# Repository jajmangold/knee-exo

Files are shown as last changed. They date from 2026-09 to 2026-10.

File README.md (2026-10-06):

<div align="center">

# Powered Knee Orthosis

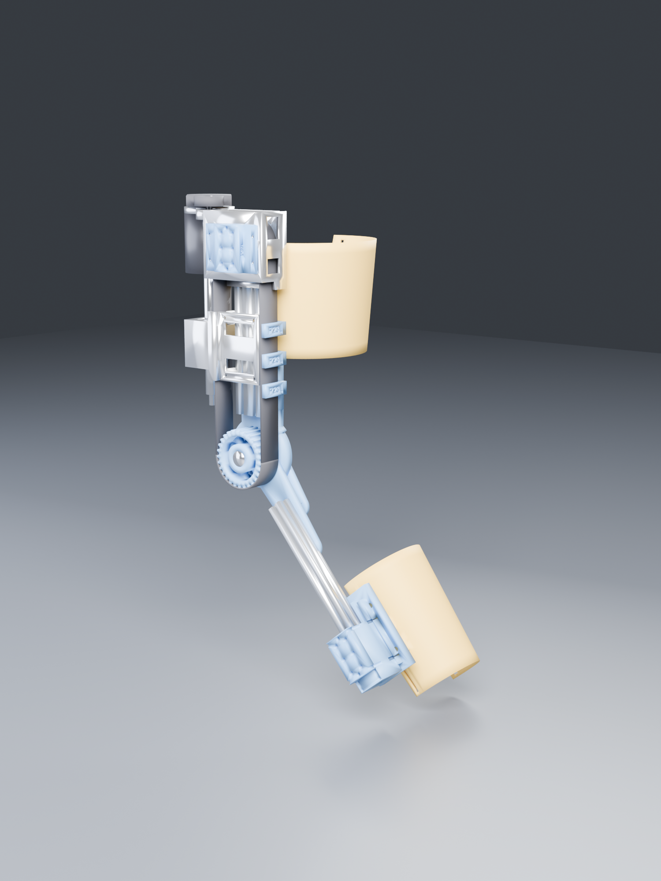
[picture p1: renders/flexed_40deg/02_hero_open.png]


<sub>Cycles render · 512 samples · the CAD itself is below</sub>

**28.2 N·m** · **36.92 mm moment arm, constant at every angle** · **86 mm proud of the knee** · **0 clashes in 107 poses**

</div>

---

> [!WARNING]
> **This is not a validated medical device.** No FEA has been run — every number here is a
> hand calculation, and the ones that matter are shown so you can check them. Cuffs are
> sized nominally for 1.75 m / 80 kg **against a cone phantom, not a measured limb** — see
> the cuff section below. Do not fit this to anyone without a clinician in the loop and a
> bench test under the loads listed.

## The problem

A patient a year out from knee surgery, struggling with walking and — particularly —
stairs. Stair ascent is the hard case: it demands the largest knee extension moment of any
activity of daily living, roughly **1.05 N·m/kg**, and it is exactly where a weak knee
buckles.

The target is **~30% assist**, not replacement. At 80 kg that is **28.2 N·m**, over a range
of motion of **−2° to 104°** — full extension to a deep enough flexion to sit down.

Everything else in this repository follows from those two numbers.

---

## It moves like this

A full flexion cycle, 0° → 104° → 0°, from 32 poses exported straight out of FreeCAD and
rendered in **Cycles**. Left: the mechanism. Right: the same cycle with the fairings on.

<div align="center">
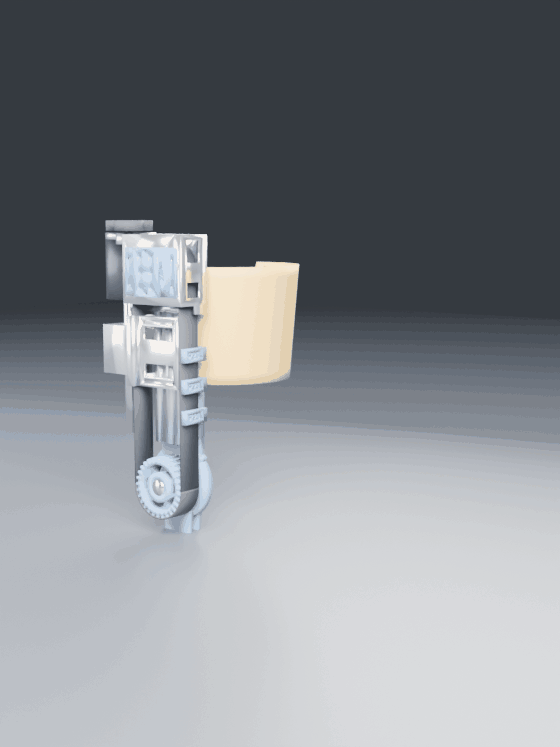
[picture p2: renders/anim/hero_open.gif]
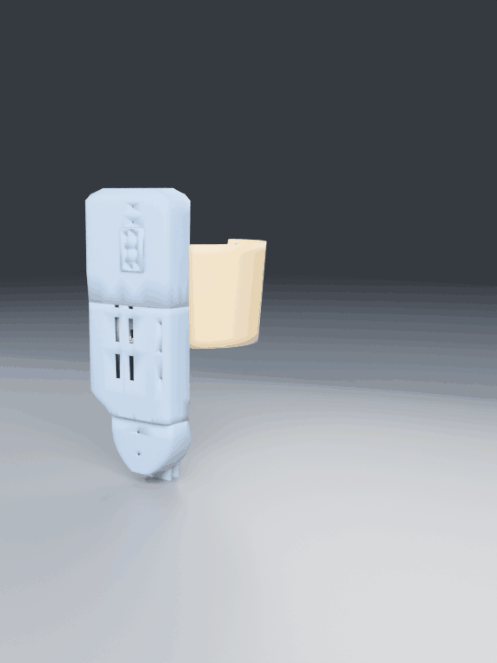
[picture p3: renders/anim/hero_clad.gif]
 
</div>

Watch the single carriage in the left animation. It is clamped to one strand of a closed
belt loop running over two identical 29T pulleys — the knee capstan and an idler. Move the
clamp by *d* and the belt circulates by *d*, turning the knee by *d/R*. That is the whole
idea, and it is why one screw does what two opposed ones used to.

<div align="center">
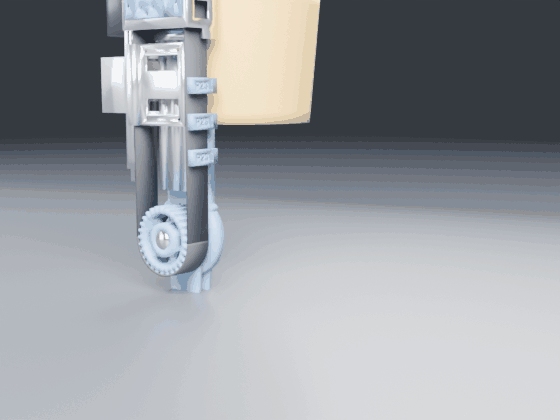
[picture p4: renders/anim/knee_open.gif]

</div>

---

## How it works

<div align="center">
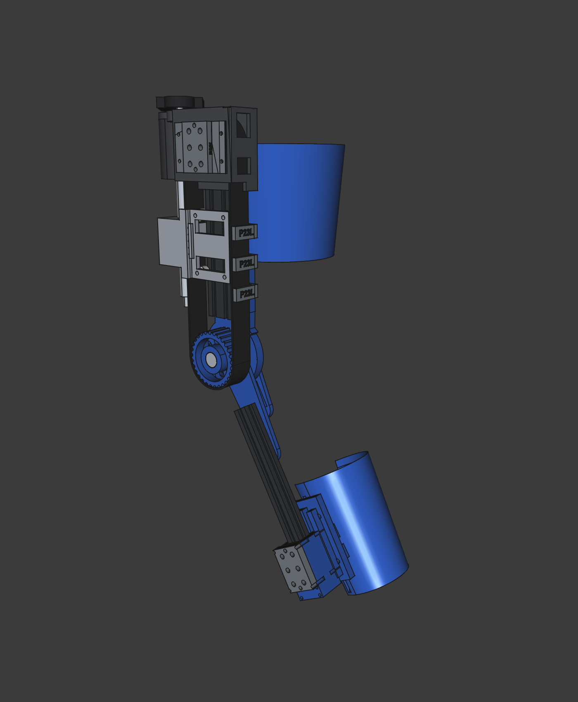
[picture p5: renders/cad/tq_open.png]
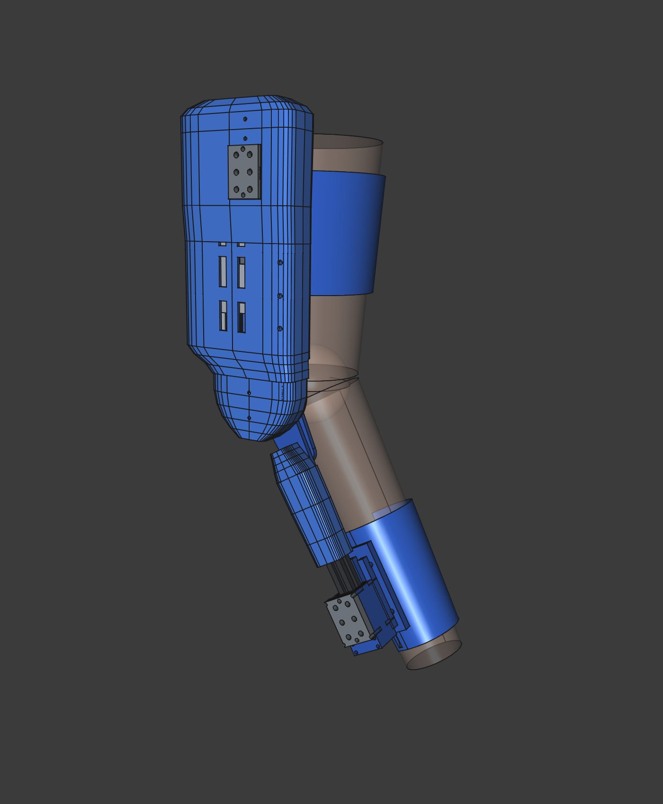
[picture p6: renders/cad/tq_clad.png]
 
<br><sub>FreeCAD viewport · mechanism, and the same thing clad on the reference limb</sub>
</div>

A **belt capstan** at the knee, driven by **one ball screw** through a closed belt loop:

| | |
|---|---|
| **Axes** | +Y proximal, **Z is the knee axis** so Z is medial-lateral, +X posterior. This is a **lateral upright** — the whole device hangs off the outside of the leg |
| **29T HTD-8M pulley** | concentric with the knee pin, integral with the shank hinge fork |
| **A second, identical 29T pulley** | an idler on the centreline at Y 255. Equal pulleys are what put both belt strands at exactly X = ±36.9 |
| **Closed HTD-8M loop, 742 mm** | over those two pulleys. Loop length is `2πR + 2·Y_idler`, independent of carriage position |
| **One carriage, clamped to one strand** | move the clamp by *d* and the belt circulates by *d*, turning the knee by *d/R* |
| **One SFU1610 RH screw at X = −62** | no left-hand thread anywhere in the build |
| **20×40 V-slot rail, 151 mm** | aluminium V-wheel gantry on mini wheels at the \|X\| 20 corners |
| **1:1.6 overdrive, motor → screw** | 32T : 20T HTD-5M. This is where the ratio is set, not the idler |
| **C6374 170 Kv BLDC + MKS XDRIVE MINI** | ODrive v3.6 clone, torque control only, never position |

Total ratio **14.5 : 1**. The idler does not gear anything — it carries no torque, and
`2πR/lead` with the belt loop alone gives 23.2 : 1. The **link belt** supplies the rest,
and it is the right place to do it: sitting on the motor side of the ball screw's own
mechanical advantage, it carries 85 N where the capstan loop carries 764, so gearing there
costs the belt, the nut, the screw and the idler bracket nothing at all. That is what
finally reached the 14.5 : 1 this design wanted, without an SFU1616 — see
[`scripts/404_link_ratio.py`](scripts/404_link_ratio.py). What the second pulley buys is
the *return path* that lets one carriage do the work of two. How that came about, and the 725 g it saved, is
[further down](#where-this-design-is-weak).

### Why the differential is exact, not approximate

This is the part worth understanding, because it is what makes the whole architecture work.

Belt length from anchor A, around the pulley, to anchor B is:

```
L = Ya + πR + Yb
```

With a **fixed 180° wrap**, `πR` is a constant, so conservation of belt length reduces to:

```
Ya + Yb = const
```

Two equal-pitch left- and right-hand screws on one shaft give exactly `dYa = −dYb`. That
is not an approximation of the constraint — it **is** the constraint, expressed in
hardware. The belt cannot go slack and it cannot be over-tensioned by driving the motor,
because the mechanism has no way to change `Ya + Yb` at all.

Here is that being true, in the model. Same camera, same scale, orthographic; only the
knee angle differs. Watch carriage **A** (left) and **B** (right) trade places:

<div align="center">
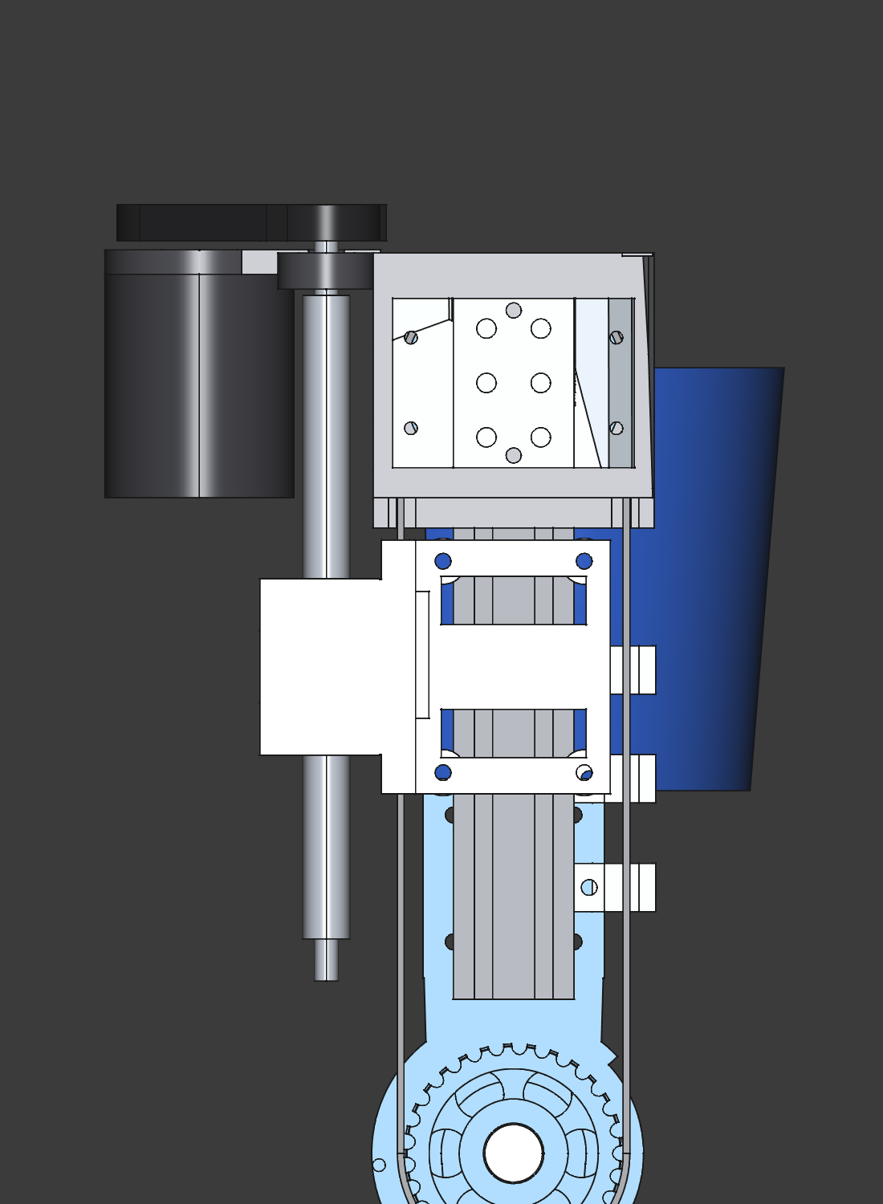
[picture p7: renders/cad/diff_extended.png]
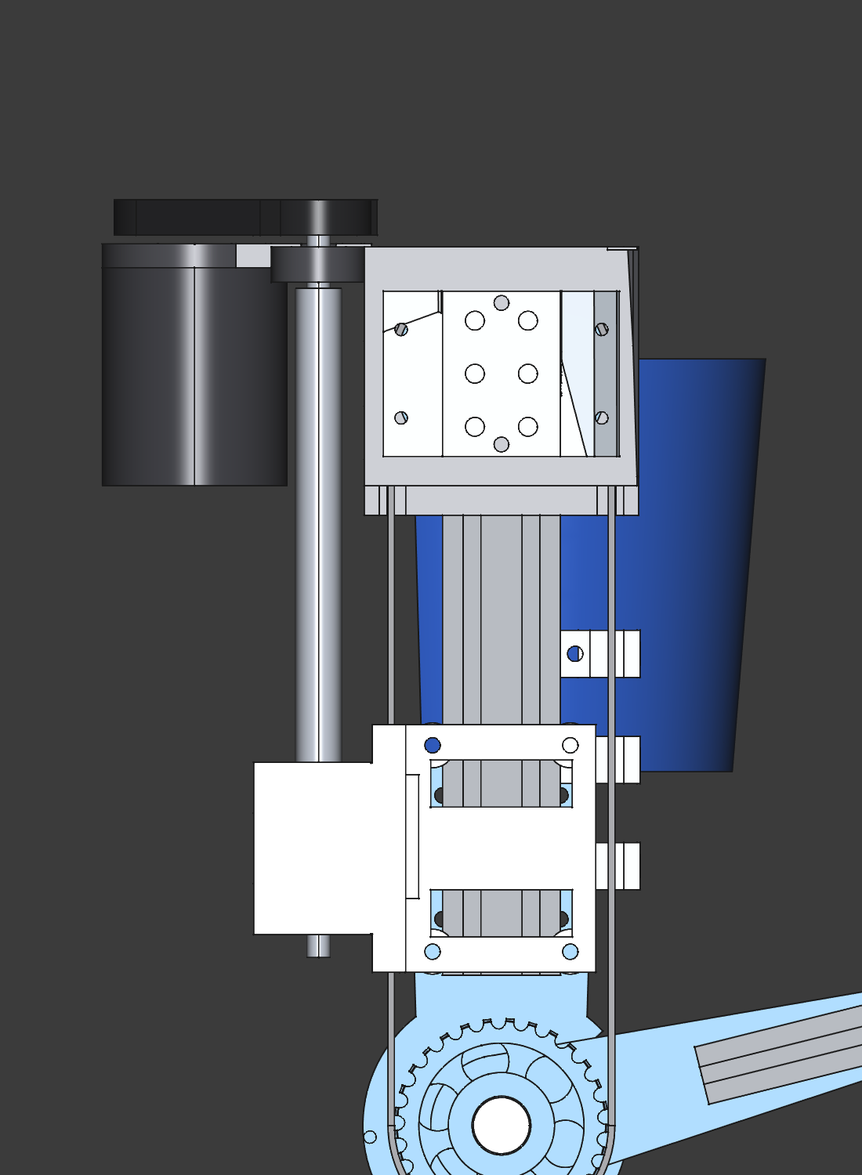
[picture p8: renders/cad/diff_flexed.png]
 
<br><sub>FreeCAD · full extension (θ = 0°) and full flexion (θ = 104°).
A drops 68.3 mm, B rises 68.3 mm, the sum never moves.</sub>
</div>

Verified constant at **242.00 mm** across all 107 poses, and re-checked on every one of the
32 animation frames above:

```
f00 theta   0.00  carrA 152.00  carrB 138.00  sum  242.00
f07 theta  41.86  carrA 125.03  carrB 164.97  sum  242.00
f15 theta 103.00  carrA  85.62  carrB 204.38  sum  242.00
f23 theta  62.14  carrA 111.95  carrB 178.05  sum  242.00
```

**This only works because both runs are parallel.** With an angled run, `Ya + Yb` becomes
nonlinear in θ and the two rigid screws fight the belt. Parallel runs are not a styling
choice; they are load-bearing on the maths.

### The second gift: a constant moment arm

<div align="center">
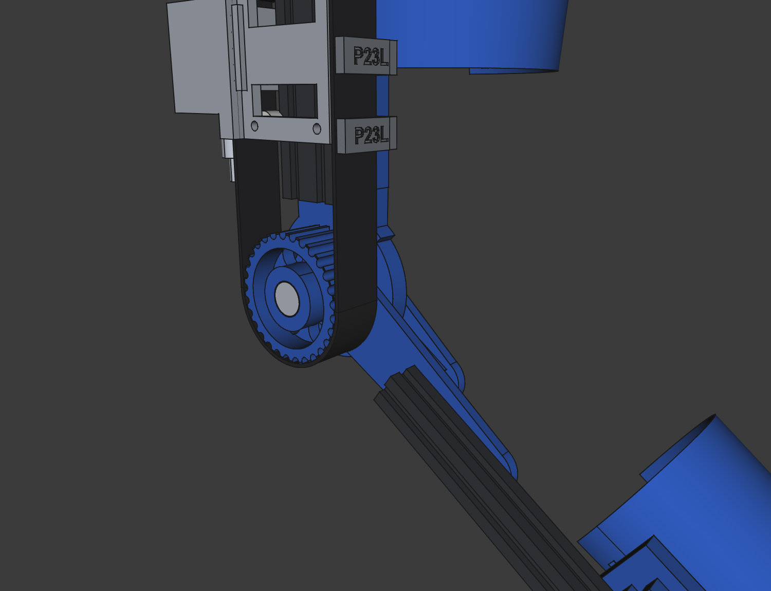
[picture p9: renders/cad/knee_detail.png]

<br><sub>FreeCAD · the 29T capstan, the yoke, and the 180° wrap</sub>
</div>

A capstan's moment arm is its pitch radius, and a pitch radius does not change with angle.
So the device delivers **36.92 mm at 0° and 36.92 mm at 104°** — no dead spots, no torque
curve to compensate for in software, no linkage singularity. Compare a slider-crank, whose
effective arm collapses towards the ends of travel; that was the first architecture tried
here, and it is in the graveyard below partly for this reason.

---

## Four architectures that did not survive

Each of these was **built and measured**, not discarded on paper. The number in the last
column is the one that killed it.

| # | Approach | Why it died | Killer number |
|---|---|---|---|
| 1 | Rigid rod + rod ends to a clevis | Clevis put the full load in tension across two M5 T-nuts, over a 75 mm path crossing two bolted joints | **1269 N**, SF **1.16** |
| 2 | Pure belt drive, motor → knee | A single stage cannot give the ratio. 65T/14T = 4.67:1 needs 6.04 N·m from a motor that peaks at 3.5 | **6.04 vs 3.5 N·m** |
| 3 | Screw + belt + constant-force spring | Spring was pure parasitic loss, gave an unpowered flexion bias, and a skipped tooth loses position permanently | **119 N** loss, **4.2 N·m** bias |
| 4 | C-Beam 80×40 rail | Belt runs are 71 mm apart but the rail half-width is 40 mm, so the belt had to be *lifted over* the rail — giving a 57 mm hub cantilever | pin **SF 1.01**, hub **SF 0.51** — failing |

Architecture 4 is the instructive one. Switching to a C-beam looked like an upgrade: a
stiffer rail, an enclosed channel to hide the belt in. But the C-beam is *wider* than the
20×60, and once the rail is wider than the belt run spacing, the belt has nowhere to go but
over the top. That 57 mm cantilever took the PETG hub to a **safety factor of 0.51** — it
would have snapped.

The fix was to go **back** to a narrower rail and run the belt down beside it. Current
state, with the belt at the same height as the rail:

| | C-beam, belt lifted | 20×60, belt beside |
|---|---|---|
| Hub moment | 62.2 N·m | **18.5 N·m** |
| Knee pin | M10, 633 MPa, SF 1.01 | **M12, SF 5.9** |
| PETG hub | 29.4 MPa, **SF 0.51** | **SF 3.7** |

### The measurement that caused it

I had been assuming for some time that the two belt runs partly cancel at the pin. They do
not. **Both runs leave the pulley on the proximal side, so their tensions add** — 764 N of
differential plus 150 N of pretension on each side gives **1091 N net into the knee pin**.
Checking that one sign is what exposed the lifted-belt layout as unbuildable.

---

## Two findings worth keeping

**The seat law.** Any point on the shank swings to approximately its own radius
*posteriorly* at 90° flexion. So if you do not want a part digging into a chair when the
patient sits, keep its radius from the knee axis below the seat clearance. This caps the
pulley at **R ≤ 52 mm** — the 36.92 mm capstan passes easily, while the old rod pivot at
**R = 74.7 mm** did not, and that is why sitting down in architecture 1 was unpleasant.

**Belt tension cannot be servo-controlled, and never could.** The shaft fixes `Ya + Yb`, so
turning the motor changes tension *not at all*: there is no control authority, and no
sensor can close that loop. Pretension is invisible at the motor too, because it pulls both
carriages distally and the opposite screw hands cancel the torques exactly.

Worse, the differential is **too stiff to hold pretension**. 150 N is only 0.27–0.53 mm of
belt stretch, while a new HTD belt beds in by 0.7–1.8 mm — so the pretension would simply
vanish during break-in, with nothing able to take it up.

Hence the **sprung anchor**: 3 mm of travel at ~500 N/mm, which absorbs bedding-in in one
twentieth of the travel the abandoned constant-force drum needed. Cost: 1.58 mm of lost
motion, **2.45° of knee angle**. Bonus: a Hall sensor on that slide reads
its deflection as **live belt tension**, which is the only tension measurement the machine
can make.

---

## Drivetrain

Everything below is derived in [`scripts/300_drivetrain.py`](scripts/300_drivetrain.py) —
one file, so there is a single place to change an assumption.

### The screw lead is the biggest open decision

Reflected rotor inertia scales with the **square** of the total knee→motor ratio. This is
what the patient feels whenever the motor is off: a dead battery, a fault trip, or simply
the free-swing phase of every single step.

| Screw | Ratio | Screw revs over ROM | Reflected J | **vs. the limb's own J** | Peak current | Nut OD |
|---|---|---|---|---|---|---|
| SFU1605 | 46.4 | 13.66 | 0.667 kg·m² | **2.22×** | 12.4 A | 28 mm |
| **SFU1610 — built** | 23.2 | 6.83 | 0.167 kg·m² | **0.56×** | 24.8 A | 36 mm |
| **SFU1616 — target** | 14.5 | 4.27 | 0.065 kg·m² | **0.22×** | 39.7 A | 36 mm |
| SFU1620 | 11.6 | 3.42 | 0.042 kg·m² | 0.14× | 49.6 A | 40 mm |

At **SFU1605 the leg would feel roughly three times as heavy to swing as it does bare.**
For someone already struggling to walk, that is a worse device than no device at all.

And you cannot gear your way out of it. Only the **total** ratio matters, so "SFU1620 plus
a 4:1 reduction" is inertially identical to SFU1605 direct. The only levers are a lower
total ratio (which costs motor current) or a lower-inertia rotor.

**SFU1610 is the right answer, and it is what the model now carries.**

This used to carry a caveat that the 1610 nut fouled the belt by 1.1 mm and the screws had
to move out to ±62. That was wrong, and wrong in an instructive way: it compared the nut
and the belt *projected onto the X axis* — 58 − 18 = 40 against the belt's outer face, taken
then as 41.1 and since [`423_belt_envelope.py`](scripts/423_belt_envelope.py) as **38.46** — and
never checked whether they share any length. They do not. The nut sits at
`carrA + 36` and its belt run ends at `carrA − 24`, a constant **60 mm apart at every
pose, by construction**. Swept over all 107 poses the overlap is **0.000 cm³ for OD 28,
OD 36 and OD 40 alike**.

What *does* run alongside the belt is the screw shaft, and at r = 7.9 it stays clear until
|X| < 49.

Building it ([`240_nut1610.py`](scripts/240_nut1610.py) and
[`241_fixups.py`](scripts/241_fixups.py)) took three changes, two of which only the sweep
found:

- **The carriage body** has to grow to X 34…80, Z 84…128 to capture a 36 mm bore with a
  3.8 mm wall on all three faces.
- **Its top-outboard corner then clipped `P21` by 0.495 cm³** — *trap 2 again*: a
  superellipse is not 84 wide everywhere, and by Z = 128 its half-width has fallen to 83.3
  and its inner wall to ~80.3. Rather than guess a chamfer, the carriage is simply **cut by
  `P21`**. The fairing's section is constant over Y 58…300, which covers the whole travel
  band, so one cut clears every pose and the chamfer matches the fairing exactly.
- **Carriage B then hit the thigh cuff, 8.67 cm³** at X 34…70, Z 84…88. The body had to
  drop to Z = 84 for the nut and the cuff tops out at 88 — but only on the +X side, where
  it wraps further round the limb, which is why carriage A was clean and only B clashed.
  The cuff bolts to the rail's medial face at |X| < 30, so the wrap-around material out at
  X 32…82 gets a corridor cut through it.

Swept over all 107 poses: **zero hard-part clashes**, knee standoff unchanged at 86 mm.

### Motor

| | |
|---|---|
| Motor | C6374 outrunner, **170 Kv**, 14-pole (verify: count the magnets) |
| Torque constant | 0.0562 N·m/A |
| Shaft torque | 1.39 N·m at 10 mm lead · 2.23 N·m at 16 mm |
| Peak current | **24.8 A at 10 mm** · 39.7 A at 16 mm |
| Peak speed | 1160 rpm at 10 mm · 725 rpm at 16 mm |
| No-load at 38.4 V | 6528 rpm — we use 18% of it |
| Controller | MKS XDRIVE MINI, ODrive v3.6 clone, 12–56 V, ~40 A, fw 0.5.1 |
| Owned | 4 motors, 4 drives — a bilateral build is a mechanical parts question only |

### Energy

Lifting 80 kg by a 170 mm stair rise is 133 J. The knee does about half; the exo supplies
40% of that at 55% wall-to-shaft — so **49 J per step, electrical**.

| Use | Draw | Hoverboard 360 Wh | Ebike 504 Wh |
|---|---|---|---|
| Stair climbing, 1 step/s | 57 W | 6.4 h | 8.9 h |
| Level walking | 23 W | 15.5 h | 21.6 h |
| Mixed daily use | 12 W | 30.9 h | 43.3 h |

**Energy is not the constraint.** Both packs comfortably outlast a day, so the battery gets
chosen for its *mount*, not its capacity — see [`docs/BOM.md`](docs/BOM.md) §7.

---

## Packaging

<div align="center">
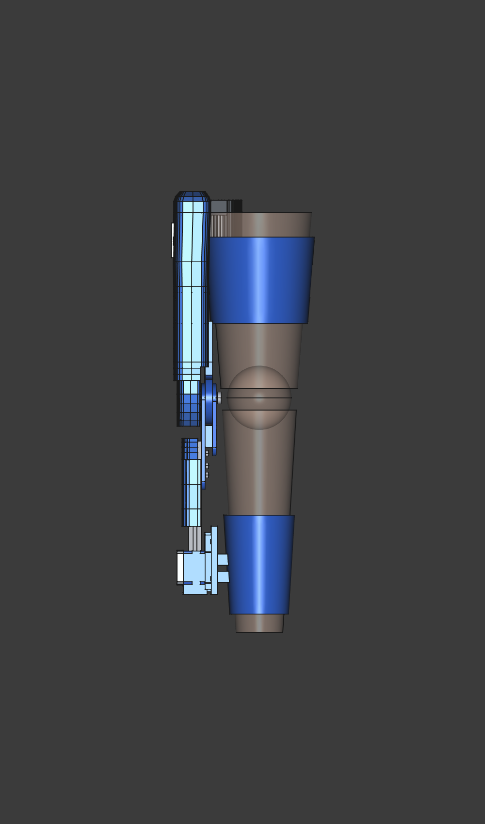
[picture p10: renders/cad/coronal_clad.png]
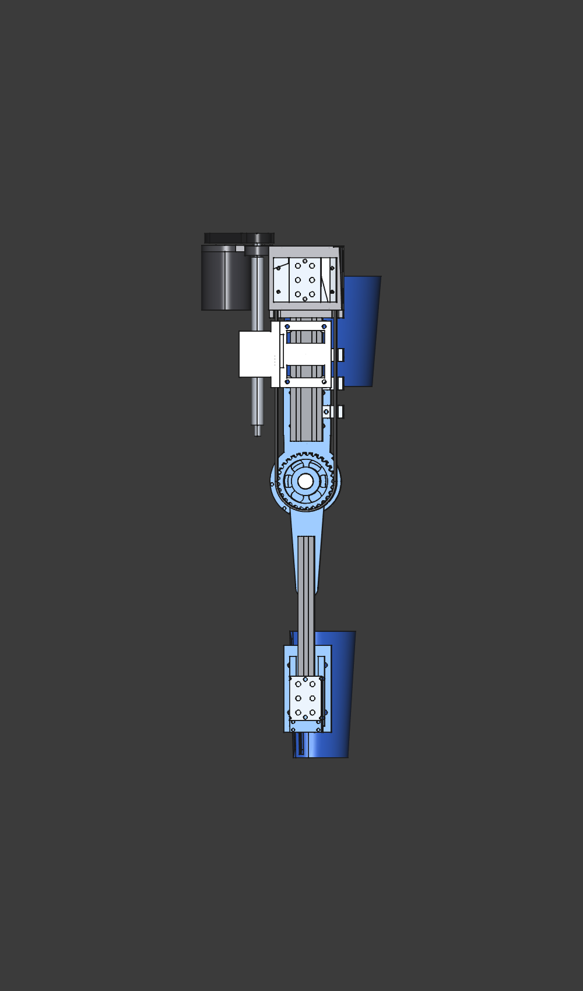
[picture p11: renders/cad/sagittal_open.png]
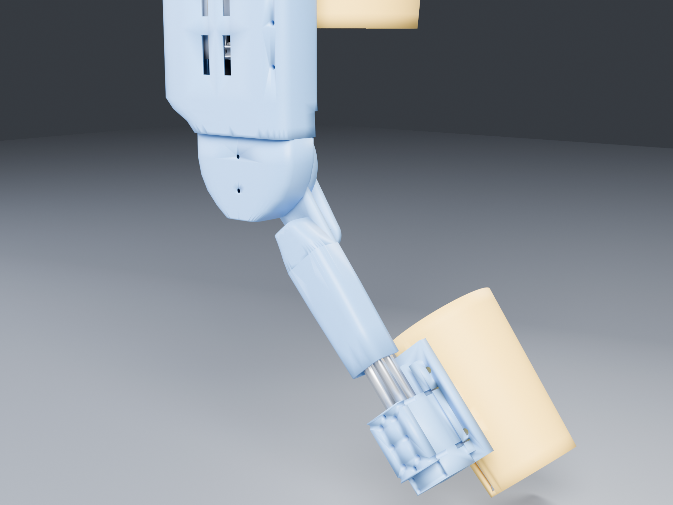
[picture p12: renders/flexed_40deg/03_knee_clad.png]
  
<br><sub>FreeCAD orthographic coronal and sagittal — the model itself · then the knee clad, at 40° of flexion, in Cycles</sub>
</div>

The device sits **86 mm proud of the knee** clad, 80 mm bare — unchanged by the one-screw
rebuild, which was the main thing to confirm when the rail narrowed. That left-hand
orthographic sagittal view is the one that matters — that thin edge is the number deciding whether it
fits under trousers.

### The enabling observation

The pulley's **inside** is what swings. Measured across the full sweep, nothing moving
occupies r = 41…70 mm at Z = 96…126, and once the knee pin head is recessed flush at
Z = 126, nothing at all sits above that plane. So the belt and the pulley's outer face can
be **completely enclosed by static covers** tied into the thigh fairing — no moving shroud,
no sliding seal.

Two changes were needed first, both about **swept** volume rather than static shape:

- **A4's proximal end moved from Y = −45 to Y = −70.** Its inner corner swung at r = 45 mm,
  leaving only **3.88 mm** above the belt. At −70 it swings at r = 70.7 mm, giving
  **28.9 mm**. The length was doing nothing — the fork bolts are at Y −90…−125 and the
  socket engages at −208…−318.
- **The yoke's disc went back to a full r = 47 mm**, with the fork outer cheek's *swept
  sector* (r 43…49 mm, angles 241°…43°) cut away. An earlier r = 30 had been cut "to clear
  the belt wrap" — but the yoke lives at Z 76…88 and the belt at Z 96…126. Radius was never
  the constraint. The cut was right; the reason was wrong, which meant it was cut in the
  wrong place.

### Fairing geometry

Sections are **superellipses at exponent 5.5** — a rounded rectangle, not a slab:

```
(x/a)^5.5 + (z/b)^5.5 = 1
```

The thigh fairing flares from 58 → 84 mm half-width over Y 28…58 on a smoothstep, carries
eight vent slots, and mounts on a **central spine into the rail's middle outboard slot at
X = 0** — the one channel nothing else uses, since the carriages take X = ±20 outboard and
X = ±30 side. So the mounts are never swept.

| Part | Covers |
|---|---|
| `P20_KneeCap` | an inverted-U channel — walls at X ±50, roof at Z 132 — enclosing both belt runs and both in-running nips |
| `P21_FairingThigh` | one canopy, Y 28…180 with side skirts to 206, over the screw, the nut, the carriage and both belt runs |
| `P22_DriveCap` | Y 178…334 over the bracket, the idler and the link belt. Its Y 180 station **is** P21's end section, so the two are flush with no step |
| `P25_MotorNacelle` | Y 206…334 over the motor, the link belt and the controller. A tube over the motor, because it has to be — see below — opening into a superelliptical nose over the board and ending in P22's own proximal plane |

**There is no shank cover.** There used to be one, `P24`, over the shank member at Y −208…−66. The shank rail then moved in-line under the knee joint ([`430_shank_inline_build.py`](scripts/430_shank_inline_build.py)) and there was nothing left for it to fair, so it is deleted rather than redrawn. [`406_coverage.py`](scripts/406_coverage.py) is what decides whether that is acceptable, and it reports **0 of 187 rays** reaching a moving part at 0°, 30° and 104°.

`P22` and `P25` are **two printed parts of one surface**, not two shells that happen to
meet. They are built as (cap outer ∪ pod outer) − (cap inner ∪ pod inner) and then split
along the pod's outer face, so they tile that wall exactly: 160.2 + 82.9 = 243.1 cm³,
100.0 % accounted, 0.0000 cm³ overlap. The earlier pair each cut itself back to the
*other's outer* surface, which deleted every point lying in both walls from both parts — a
thin void running the length of the seam, belonging to neither. Nothing caught it, because
an interference sweep looks for material in two places at once and this was material in
neither.

The motor pod is a round tube and cannot be anything else:

| | mm from the leg axis |
|---|---|
| motor axis | 121.1 |
| can face (axis − 31.5) | 89.6 |
| thigh surface + 3.0 comfort clearance | 87.9 |
| **room for a cover between them** | **1.7** |

An attempt to merge the cap and the pod into one lofted n=5.5 section failed on this. A
section large enough to hold both lobes has its floor 60 mm below the hardware, and the
limb cut then deletes that floor across the whole central span — at X −55, where the ball
screw runs at Z 103, the small cap's floor is at Z 78 and survives the cut at Z 68.6, while
the merged section's floor is at Z 22 and goes. `406_coverage.py` scored the merge at 16
exposed rays against 0 for the pair: the screw and the motor both became touchable. An
n=5.5 section is wider on its diagonals than a circle too, so no superelliptical pod of any
size clears the thigh at that bearing either — once the 3 mm wall is counted, even **n = 2.5**
is inside the limb (pod face 83.8 against a thigh at 84.9), and only the circle survives, at
86.1. Offsetting the section outboard does not rescue it: the inboard half-size then has to
grow by the same amount and the diagonal gets worse. What the pod got instead is a **faired foot**
— a raised-cosine flare over the +12…+100° window about the motor axis, 12 mm at its peak,
so the tube grows out of the cap's flank rather than piercing it — and a **domed nose**,
tapered over Y 209…214.5 to a 19 mm blunt end. The window costs nothing: a ray leaving the
motor axis above about +15° never reaches the thigh, and flare that ends up inside the cap
is already in the union. Closest approach to the limb is unchanged at 86.1 mm.

`P20` looks like a small nose piece in the renders and is easy to write off. The material
map at Y=0 shows what it actually is:

```
      X  -60   -50   -40   -30   -20   -10     0    10    20    30    40    50    60
Z 124      .     #     .     .     .     .     .     .     .     .     .     #     .
Z 128      .     #     .     .     .     .     .     .     .     .     #     #     #
Z 132      .     #     #     #     #     #     #     #     #     #     #     #     #
```

Two walls at X ±50 and a roof at Z 132, with the belt runs at X ±36.24…38.46, Z 96…126
sitting inside that channel. It is the only guard on either nip — `P21` starts at Y=28 and
the nips are at Y≈0 — and the channel is open only medially, through an 8 mm slot between
the yoke at Z 88 and the shroud at Z 96.5, which no finger fits through.

### How much leg this fits, and the one adjustment it has

Asked at the bench: could the motor nacelle swing out and lock further from the leg, for a fatter
leg? The nacelle *is* the part closest to the limb, so the instinct was right — but answering it
turned up something the whole repository had been blind to.

**Every limb cut here is a cylinder and the leg is a taper.** `399_drivecap.py` carves the
cladding with cylinders of r 87.9 and r 85.0 about the limb axis, which is correct at the top of
`REF_Thigh` and 20 mm too generous at the knee. A cylinder cannot express "3 mm clear of the leg"
on a conical leg, so nothing ever asked whether the **3 mm neoprene sleeve** of BOM S5 fits
underneath. [`438_limb_clearance.py`](scripts/438_limb_clearance.py) asks it, against the limb's
own measured radius at each station:

| | clearance to limb + sleeve + 0.5 mm |
|---|---|
| `A3_Motor_6374` can | +1.6 mm |
| `P27_ControllerMount` | +1.6 mm |
| the controller board | +4.1 mm |
| `A7_DriveBracket_Idler` | **0.0 mm** |
| `P25_MotorNacelle`, as first drawn | **−2.9 mm** |

So nothing in the drivetrain was too close. The offender was the **cover over the controller**,
and its cavity had 4.5 mm of slack over the board on that side: it had been sized against the
r 85.0 cylinder, which is the bare leg at the top of the taper. Flattening its section — 80 × 66
at n = 10 instead of 78 × 72 at n = 6.5, shallower toward the limb, the corner reach bought back
from the exponent rather than the semi-axis — cleared it, and made the part smaller.
[`439_limb_trim.py`](scripts/439_limb_trim.py) took the last 0.64 cm³ off the two drive shells,
and the check now reports nothing but the cuffs touching the limb.

**The swing was built and reverted, and it is worth keeping the arithmetic.** Swinging the motor
about the **screw's** axis is the only motion that leaves the link belt's 60.8 mm centre distance
untouched, so it needs no tensioner; the belt's pull on the motor acts along the line to the pivot,
so the lock would carry none of it. 10° buys 10 mm of radius and a bare can is clear of every part
to 10° (only at 20° does it graze `P22` by 0.5 cm³).

| swing | motor at | gap at the can |
|---|---|---|
| 0° | X −104, Z 62 | 7.6 mm |
| 10° | X −111, Z 70 | 17.7 mm |
| 20° | X −117, Z 79 | 27.3 mm |

What it costs is the pod: that tube is wrapped concentrically around the can, so moving the can
pierces its wall (12.8 cm³), re-centring the pod moves the seam it shares with `P22`, and
re-centring it by fusing a new tube put 51 cm³ into a cosmetic shell. Swinging the motor to fix a
cover is the wrong lever. But if a tape measure on the patient says the whole drive end has to
stand further off — which is what a genuinely fatter leg needs, since the frame's standoff is set
by the cuff and moving *that* carries the knee pivot away from the bone with it — the swing is one
constant in [`433_drive_flip.py`](scripts/433_drive_flip.py) and the numbers are in
[`437_leg_size.py`](scripts/437_leg_size.py).

Two measurement lessons from the same afternoon, both recorded in the files: a predicted 0.7 mm of
surviving wall came out at 2.90 mm because the deepest intrusion was an *edge* at bearing +149°
rather than the closest face — right about the geometry, wrong about where it mattered — and a
wall measured with one ray through a sliver's bounding-box centre read 0.00 mm because the ray
missed the material entirely.

### Where it stops

Honest limits, because they are the parts a photo hides:

- The fairing is **open below Z = 92 near the centreline**, where the limb is 3 mm away and
  there is no room for a wall. It is *not* open further out: the undersides follow the limb
  (a cylinder 3 mm proud of `REF_Thigh`, not a flat plane) and each side carries a skirt
  down to Z 83, because `406_coverage.py` found the gantry and the V-wheels reachable at
  ±14° through the longitudinal slot either side of the rail.
- **Y −66…−46 is a moving gap** — 20 mm of bare hinge plate, down from 55. A rigid shell
  here has to sweep past the static thigh fairing, so the remainder can never be closed
  and wants a fabric gaiter. See below.
- The motor cover **skims the quadriceps** — 1.2 mm off a nominal thigh against the 3.0 mm
  the rest of the cladding gets. There is no way around it: see the table above.
- `406_coverage.py` reports **0 of 187 rays** reaching a moving part first, at each of three
  poses. That is the strongest statement available here, and it is still only 11 bearings ×
  17 stations — it is a sampling, not a proof.

A collision the sweep caught only once someone read its output properly: the skirts drove
straight through `P1_KneeYoke` — 5.323 cm³ in two symmetric lumps at X ±20.4…30.0, Z 82.6…88,
for 74 mm of their length. The yoke is a 12 mm plate at Z 76…88 reaching Y 124, the skirts
hang to Z 83, and the hand-written box that was supposed to clear the fork cheek only covered
Y 20…50. It had sat in the flagged-pairs list for a full 107-pose run looking like one of the
deliberate bonds (`P21`↔`P23a/b/c`, 0.687 cm³ each, which are meant to merge).

The first fix made it worse in a way worth recording. Cutting a *box* over the yoke's
bounding extent also removed the canopy's own floor in that band — the 0.7 mm of skin
between the limb cut at r 87.9 and Z 88.6 — and that floor was the only thing between the
skin and the ball screw at −28° over Y 76…112. Coverage went 0 → 3 and named it. The cut now
follows the yoke's actual shape, dilated 0.6 mm by translated copies, which costs 6.7 cm³ of
skirt and leaves coverage at 0.

`397_recladding.py` now checks `P21` against the yoke, the hinge plate and the shroud at
build time, where it costs a second, rather than at the end of a twenty-minute sweep.

### The cuffs, which had never been calculated

Everything upstream of the cuffs — screw, bracket, belt, wheels — was sized by calculation.
The thing that actually touches the patient was not, and when
[`408_cuff_loads.py`](scripts/408_cuff_loads.py) was finally pointed at it, it found that
**neither cuff fitted the limb.** Both phantoms are cones; both cuffs were cylinders.

| | before | after |
|---|---|---|
| thigh cuff | floated over its distal half, bore on a **47 mm band at the proximal rim** at **~40 kPa** | conical, bears across all 140 mm at **12.5 kPa** |
| shank cuff | **never touched the limb** — 15–23 mm of air, closest approach 7.78 mm | conical, 160 mm wide, **12.2 kPa** |

40 kPa against a ~15 kPa sustained-comfort ceiling, concentrated at a shell edge, on a limb
with post-operative circulation, is not a comfort problem — it is how braces injure people.

The sweep had been reporting this for months and nobody read it. It flags
`P5_ThighCuff ∩ REF_Thigh` at 0.836 cm³ every single run, and it has **never** flagged
`P7_ShankCuff ∩ REF_Shank`. The absence was the finding.

Three other things came out of the same pass:

**The load that should drive the design is not the assist.** All 3.78 kg hangs lateral,
~95 mm off the limb axis, which is a **constant 3.52 N·m roll torque** trying to rotate the
brace around the leg — present with the motor off. Resisting it by friction needs ~31 N of
strap tension per cuff, *repeatably*, because if it is not repeatable the device sits at a
different roll angle each day and the knee axis stops lining up with the patient's.

**A neoprene sleeve is the skin interface**, not an EVA pad. It raises the governing friction
coefficient from 0.4 to ~0.6 worst case, so the strap needs **21 N instead of 31 N**; it
bridges the shell rim instead of letting it dig; it moves the sliding interface off the
patient; and it washes. What it cannot do is bridge a 20 mm gap — a compliant layer cannot
fix geometry, which is why the cones were still necessary.

**The closure is 38 mm nylon webbing, 2:1 through a D-ring into a cam buckle**, with a
side-release buckle in the loop. Not lace: at 31 N across the open side of the cuff a 3.5 mm
lace is ~90 kPa on soft tissue against 8.3 kPa for 38 mm webbing, so a laced brace needs a
separate tongue and webbing is its own. And this is a **powered** device — one squeeze gets
it off in ~2 s, against ~8 s to find and release a cord lock. That is the only safety
argument in the whole analysis and it is the one that settled it.

The shells now carry **rolled rims** at both ends, because the edge is where concentration
lands even once the cone matches, and the gap to the limb is **4.00 mm, constant across the
full width and every bearing** — sleeve plus 1 mm of donning air.

One thing the rebuild exposed: the old shank cuff sat at r 64 because that is what it took to
reach `P6_ShankSocket`, not what it took to fit a leg. It had been sized to the structure.
Sizing it to the limb drops it to r ≈ 47 and it now reaches the socket on a riser.

And one cost, stated because it is the kind of thing that only shows up on a person. The
old cuff wrapped **posterior-lateral only** (0…110° and 300…355°) and never reached the
medial side. Wrapping 200° to get the pressure down puts the shell **8.0 mm proud of the
medial skin** — 3 sleeve + 1 donning air + 4 wall, which is the floor for any cuff with a
sleeve, not something that can be optimised away. The medial envelope went from Z −76.2 to
−89.8. Thighs pass close at midstance, so this is worth watching at the first fitting; if it
catches the other leg, the trade is wrap −105° → −85° plus 20 mm more width, which lands at
12.2 kPa and is still under the ceiling.

### Why the shank looks bare, and how much of that is necessary

A fair question to ask of the renders. Measured coverage along the limb axis:

| | Hardware span | Faired | Coverage |
|---|---|---|---|
| Thigh | Y 0…320 (320 mm) | `P21` 28…206, `P22` 180…334, `P25` 178…326 | **91%** |
| Thigh, counting `P20_KneeShroud` over Y 0…28 | | | **100%** |
| Shank | Y −328…35 (364 mm) | `P24` Y −208…−100 | **30%** |

30% sounds bad and mostly is not, for three separate reasons that are worth keeping apart:

**Most of the shank has nothing to fair.** Every moving part of the transmission — the ball
screw, the nut, the gantry, both belt strands, the idler and the motor — is on the thigh. Below the knee there is a rail, a hinge plate, a socket and a cuff, and relative
to the shank *nothing moves at all*. The one genuine pinch hazard down there is the belt
entering the capstan, and `P20_KneeShroud` already closes over both nip points. So the
shank is 30% covered by length but close to 100% covered by hazard.

**The distal 120 mm (Y −328…−208) is the socket and the cuff.** Those are closed
structural shells and the interface to the limb. Putting a fairing over a cuff would be
fairing a fairing.

**The 55 mm gap is the only real hole** — and it is smaller than stated here until
recently. The claim used to be that the shank fairing "cannot start closer than Y = −100",
on the basis that a shell from −66 sweeps to X 70.3 at 104° where the thigh fairing is
already 63.5 mm wide. That is true *of a constant-section shell*, and false as a general
statement. Sweeping candidate extensions through the full ROM against all 25 non-shank
parts at 1° steps:

| Extension | Result |
|---|---|
| Constant ±24 section to Y = −80 | clean |
| Constant ±24 section to Y = −70 | 0.35 cm³ into `P21` at 104° |
| **Tapered tip to Y = −66** (±14, Z 101…117) | **clean** |
| Tapered tip to Y = −60 | 0.20 cm³ into `P20` at 104° |

So **34 of the 55 mm can be closed** by tapering the proximal tip in both width and height
so it ducks under the knee shroud as it swings, leaving a 21 mm gap.

### A static cheek covers the whole fan — and was the wrong answer anyway

All of the above treats the cover as **shank-mounted**, which is why it is constrained at
all — a shank-mounted shell has to sweep past the static thigh fairing. A **thigh-mounted**
cover has no such problem. It never sweeps; it only has to clear the shank *laterally*,
in Z. And that clearance already exists: the hinge plate tops out at Z = 126 and
`P20_KneeShroud` already reaches Z = 133, so **Z 126.5…133 is a free lateral band**.

A static cheek sector on the knee axis, r 40…108 mm, Z 126.5…133, spanning −100°…+26°,
swept against every shank part at 1° steps over the full ROM:

| | Result |
|---|---|
| vs. the moving shank (incl. reference limb) | **clean, 0 cm³ at every pose** |
| vs. static parts | 2.62 cm³ into `P20_KneeShroud` — an overlap to *merge*, not a clash |

That covers the entire 106° fan with **no gap at all**, and no gaiter. It is a single valid
closed solid. The cheek is naturally grown from `P20_KneeShroud`, which is already static
and already at the knee, and bolted through to `P1_KneeYoke` for support — the yoke itself
sits at Z 76…88, medial of the rail, so it is the right *anchor* but the wrong *side* to
grow the skin from.

The same trick closes the top. Nothing moves above Y = 312, and the motor pokes out to
Z = 149.5, past the thigh fairing's 138. A cap of X ±95, Y 310…394, Z 86…154 is clean
against everything that moves, overlapping only `P21_ShellAnterior` by 1.22 cm³ — again, a
merge.

Both were built and both swept clean. **The cheek is not in the model**, because
geometry was never the problem with it: it is a 216 mm flat plate standing off the side
of the knee. That is ugly, and — the part that actually matters — it is a snag hazard in
its own right, sticking out laterally at exactly the height that catches a door frame.
The device is supposed to stop the patient catching on things.

And what it was covering is bare *structural plate*, not mechanism. There is no pinch
hazard out in the fan; the nips are at the capstan and `P20` already closes over both.
Trading a cosmetic gap for a plate that catches door frames is a bad deal.

So the shank tip does the work instead, tapered in both width and height so it ducks
under the knee shroud as it swings, reaching **Y = −66**. `P20` already reaches −46, so
the moving gap is **20 mm**, down from 55, and a fabric gaiter covers it. The drive cap
stays — nothing swings at the hip, so it costs nothing and the motor is a spinning bell
that genuinely wants enclosing.

Building the cap turned up two things the envelope study had not:

- **The cap could not simply butt onto `P21`.** `P21` runs at a constant a=84, b=23,
  zc=115 and then closes from Y=300, while the motor starts at Y=314 already needing
  Z 86.5…149.5. There is nowhere to put the shoulder, so `P21` is trimmed back to Y=290
  and the cap takes over the last 22 mm of canopy.
- **Two constraints set when the cap's section centre may walk outboard.** Walking `xc`
  negative early pulls the posterior wall into the drive box, which runs to X=+70 until
  Y=311; necking down early puts the motor through the wall — 1.22 cm³ of it, at
  Y 370…392. The section stays full until Y=389 because the motor ends at 388.

Two lessons in one section: the shank-fairing limit was the same mistake as the yoke radius
earlier in this project — a cut made for a correct reason, then the reason generalised into
a constraint nobody re-tested. And the better answer came from asking *which frame the
cover lives in*, which is a question the original analysis never posed.

---

## Verification

[`tools/sweep.py`](tools/sweep.py) runs a **full pairwise interference sweep with no skip list** —
107 poses, every part against every other, across ten headless FreeCAD processes in **2.5 minutes**.
The GUI-driven version it replaced ([`231_verify.py`](scripts/231_verify.py)) took about 32 minutes
in twelve chunks, because the RPC server times out at 90 s per call; `freecadcmd` has no such limit
and poses are independent, so they shard.

**Current state, both legs: zero unintended overlaps.** Six pairs report contact and all six are
meant to: the three reference limb segments intersecting each other, and the three fairing mounts
bonded into the thigh shell.

The other three checks, all of which have caught something nothing else did:

| Check | What it asks | Current result |
|---|---|---|
| [`406_coverage.py`](scripts/406_coverage.py) | from the skin, looking out, is any moving part reachable? | **0 of 187 rays** at 0°, 30° and 104° |
| [`411_printability.py`](scripts/411_printability.py) | bed, overhangs, mean wall, closed mesh | **18 of 18 watertight** (17 parts + the tooth coupon), all inside 220 × 220 |
| [`413_mark_visibility.py`](scripts/413_mark_visibility.py) | is each engraved number actually hidden? | **16 of 16 covered**, both legs |
| [`tools/readmark.py`](tools/readmark.py) | …and does it read forwards? | **32 of 32 marks**, after 12 were found mirrored |
| [`417_fastener_audit.py`](scripts/417_fastener_audit.py) | does the hardware fit the holes? | **151 holes**, every one identified; no printed part left unbolted |
| [`420_mockup_audit.py`](scripts/420_mockup_audit.py) | **is each part the part, or only its shape?** | 23 features, all present — 8 were missing |
| [`438_limb_clearance.py`](scripts/438_limb_clearance.py) | **is anything inside the leg and its 3 mm sleeve?** | nothing but the cuffs. It found three things first: the controller cover 2.9 mm deep, a 0.07 cm³ sliver of `P22`, and the fact that every limb cut here is a cylinder while the leg is a taper |
| [`902_doc_audit.py`](scripts/902_doc_audit.py) | **do these documents still describe this model?** | 6 documents, 0 stale claims |

That last one exists because this README was stale in five places at once, and every one was a fact
a script can measure that had been typed in by hand: a sweep that no longer worked that way, parts
that no longer existed, a nut that had already been redrawn, guides that were no longer sliding, a
document name two versions out of date. It checks part names against the model's object list, volume
claims against the model, every relative link, the printed-part count, the engraved-mark count and
the leg suffixes, and it exits non-zero. Finding those by hand took a session; it takes twelve
seconds now, and it caught one more the moment it was written (`P2a_KneeHub`, an abbreviation of a
part whose name is `P2a_KneeHub_Pulley29T`).

### The pulley had no teeth

Every check above asks about the **shape a part occupies**. None of them asks whether that shape
does the job, and the difference is not academic: sampled at the belt plane over 360 bearings, the
29T capstan's outer radius was 35.55 mm with a spread of **0.000**. It was a plain drum. The belt
had nothing to grip, and the sweep, the coverage rays, the printability pass, the mesh integrity
test, the engraving and its visibility fan all passed it, because a drum of the right diameter
sweeps the right volume.

[`420_mockup_audit.py`](scripts/420_mockup_audit.py) asks the other question, from a hand-written
table of required features, because only a person knows what a part is *for*. It found **eight
missing features across five of the seventeen printed parts** — no teeth on the capstan, no V-wheel
holes and no belt grip on the gantry plate, no support for the ball screw's upper end, and no way
of attaching three cladding panels. A part that fails that table cannot work; a part that passes it
is not thereby verified, because the table only contains what someone has thought to write down.

Fixing it moved three things that had been wrong for months and agreed with each other:

* **The capstan's radius was not a free choice.** The rim was built at 35.552 — the pitch line
  differential deducted twice — and the first attempt at teeth simply cut from the rim as drawn, on
  the grounds that 0.69 mm is 1.8% of torque. But BOM S2b's idler is a **bought** 29T pulley, which
  measures ⌀72.48, and BOM K1's belt is a **bought** 742 mm loop, which is 2π·36.923 + 2·255 to
  0.03 mm. A belt cannot wrap 72.48 at one end and 71.10 at the other, and on the small rim the path
  is 737.7 mm, so a 742 mm belt arrives 4.3 mm long against an idler with 3 mm of travel. The
  bought parts set the radius: [`421_pulley_teeth.py`](scripts/421_pulley_teeth.py) grows the land
  to the standard 36.237 and cuts 29 grooves into it.
* **The belt was drawn 2.7 mm outside where a belt sits.** All four belt solids were a 5.57 mm band
  resting *on* the tip circle, which is self-consistent only while the pulleys are smooth drums.
  A real belt meshes: its teeth go into the grooves and its back stands 2.22 mm outside the tip
  circle, not 5.57. [`423_belt_envelope.py`](scripts/423_belt_envelope.py) redraws the backing and
  then checks the space the teeth sweep, where nothing but the two pulleys and the gantry's land may
  be — which caught two ribs of the drive bracket standing in it and the gantry's deck edge running
  through it for its whole length.
* **So the gantry's belt tunnel was 4.1 mm too wide.** The carriage already straddled the belt in a
  closed tunnel; against a real belt the slot was oversize and the belt would ride out of any mesh.
  [`424_belt_tunnel.py`](scripts/424_belt_tunnel.py) rebuilds it to the real section and cuts
  **five HTD-8M grooves at 8 mm pitch** into its inboard wall, so the belt is gripped by its own
  teeth — 153 N each, 1.5 MPa across a groove wall — and needs no clamp part and no bolts at all.

Then the same question, asked of the parts the table did **not** yet cover, found two more:

* **The knee yoke's bolts were at the wrong rail's slot spacing.** `P1_KneeYoke` had six M5
  through its 12 mm plate at X −20, 0 and +20 — which is where a **20×60** V-slot's three cells
  put their slots, and the object is still called `A1_Extrusion_20x60_VSlot`. The rail is a 20×40:
  two cells, channels at X ±10. BOM S1 says so outright — "Its 40 mm face has slots at X = ±10,
  not X = 0" — and notes the fairing spine has to move because of it; nobody checked the yoke, so
  all six bolts on the part that carries the whole knee reaction landed on solid aluminium or off
  the edge. [`427_rail_bolts.py`](scripts/427_rail_bolts.py) fills them and drills four that line
  up. The fill is exact rather than approximate, because each hole is a plain cylinder through a
  plate whose faces are planar and perpendicular to its axis.
* **The drive bracket had no fixing at all.** `A7_DriveBracket_Idler` carries the idler at up to
  1828 N, the largest single load in the machine, and ASSEMBLY step 5 says to bolt it to the top
  of the extrusion. Its entire hole inventory was 4 × M4 for the motor, the screw clearance, the
  608 seat, two idler bearing seats and the boss — **no M5 anywhere**, and 0.000 cm³ of contact
  with the rail. It does have a 10 mm plate butted against the rail's end face, square across both
  cells, so the fixing had been designed and never drilled.

Both were invisible to a hole count, which is what `417_fastener_audit.py` and the first version of
this table both did: the yoke had six M5 and passed "a bolt pattern into the thigh rail ≥ 2" every
time it ran. The check now samples the rail at the height of its channel and asks whether a bolt at
that X could enter — **laterally**, never along the bolt's own axis, because the bought rail's
mockup carries a 2 mm web across the slot centreline that a real V-slot does not have, so a ray
fired along a correctly placed bolt reports "hits material" and one along a wrong bolt can report
clear. That web is the next thing in this file's own list: a bought part's simplification that no
printed part's geometry can be checked against.

The tooth profile is the one number in the build that arithmetic cannot settle: HTD-8M is a
curvilinear form defined by arcs this repository does not have, so the groove is a half-ellipse
approximation and `TEST_ToothCoupon_3xHTD8M` — three teeth, 2.5 cm³ — is exported to be printed and
pushed onto a real belt **before** the 10-hour capstan.

> [!WARNING]
> **The first fix was itself a mockup.** The belt clamp added for the gantry extruded its groove
> along Z and then rotated it 90° about Y "to lay the groove along X", which instead turned the
> depth axis into Z: the cut was five elliptical tunnels bored sideways through the carriage, not
> five grooves across a face. Every one removed material, so the "did this cut land in air?"
> assertion passed, and the audit's own `a belt clamp` test — two cylindrical faces of 3–7 mm —
> was satisfied by the bolt holes. **Counting holes cannot tell a clamp from a colander.** Both
> checks now measure the feature: the land is scanned along Y and must step in and out by the
> groove depth, at the belt's pitch.

> [!IMPORTANT]
> A skip list hid **six real clashes** earlier in this project, including a carriage bore
> cut along the wrong axis and a telescoping joint that did not telescope. Do not
> reintroduce one. If the sweep is too slow, make it faster — do not make it blinder.

---

## Six traps that cost real time

Recorded because each one produced a *plausible* result that was wrong, which is the
expensive kind of bug.

**1. `obj.Shape` returns geometry with the placement already applied.** A read-modify-write
while a part is posed bakes the pose in permanently. This bit twice — once during a
measurement, where `Shape.Vertexes` returned a live animated pose which I then rotated
*again*. Stop any animation timer and zero every placement before touching geometry.

**2. A boolean that severs a part returns a *valid* shape**, not an error — just with
`len(Shape.Solids) > 1`. Always `assert solids == 1 and isClosed()` after cutting.

**3. Spline lofts overshoot.** `makeLoft(..., ruled=False)` bulged sections out to X ±129
instead of ±83 and self-intersected into two solids. Use `ruled=True` with closer stations.

**4. A superellipse narrows in Z at its X extremes.** Containing a box of half-size (W, H)
requires `(W/a)^n + (H/b)^n ≤ 1`, which is *not* the same as `a ≥ W`. At n = 3.4, b = 22 the
carriage needed **a = 108**; I had used 80. Carriages, cuff, rail and belt all poked through
the walls — **eight clashes, one root cause.**

**5. An inner loft must overrun the outer at both ends**, or `outer − inner` leaves a closed
end wall. Setting the shank fairing's inner to start at Y = −102, distal of the outer's
−100, produced a wall that A4 passed straight through — a constant **0.441 cm³ at every
pose**. A constant overlap across a sweep is the signature of a static modelling error, not
a kinematic one. Read the constant; it tells you where to look.

**6. `Shape.BoundBox` overshoots on lofted surfaces.** The drive cap reports a bounding
box of Y 288…399, Z 82.4…159.5 while its actual material is Y 290…399, Z 92…159.5 — the
box comes from B-spline control points, not the surface. It is exact on prisms and
cylinders, which is why it can be trusted for the ball-nut-to-belt clearances, and loose
on anything lofted. Never quote a clearance off a bounding box without confirming it with
a boolean.

---

## Guides, and why the layout spends the axis it does

> [!NOTE]
> **This section is history.** It reasons towards MGN7H blocks and a table below still says
> "MGN7H — built"; what is actually built is **four mini V-wheels** on the extrusion's corners, and
> both carriages, both MGN7 rails and the sprung belt anchor went with the second ball screw. Kept
> because the reasoning about mounting faces — and about what an interference sweep cannot ask — is
> what led to the current layout. Current state: [`396_fixes.py`](scripts/396_fixes.py).

The carriage guides were Delrin L-gibs running in the extrusion's slots, and are now
MGN7H recirculating blocks. The load case is
not the interesting part: the 914 N of belt pull goes straight into the ball screw, and
the guide only takes the couple from the 19.7 mm offset between the belt line and the nut
axis — **176 N at each end of the carriage**. Every linear guide on the market is ten
times overspecified for that.

Friction is the interesting part, and specifically that sliding friction is *unstable*:

| | Friction | Mass | Load capacity |
|---|---|---|---|
| Delrin L-gibs | **70 N** — 7.7% of belt pull | 29 g | fine on contact pressure |
| **MGN7H — built** | **1.4 N** | **95 g** (2 rails, 4 blocks) | 1.00 kN |
| MGN9H | 1.4 N | 150 g | 1.86 kN |
| HGR15 | 1.4 N | 616 g | 7.84 kN |

Beyond the 7.6% recovered, the real argument is stick-slip: a breakaway force different
from the running force, and a μ that wanders with wear and temperature. The whole control
plan is to start at 10% assist and creep up under a physio's supervision, and notchy
low-level torque makes that hard to tune and unpleasant to wear.

**HGR15 is the wrong size** — 616 g for capacity nobody needs.

### Where the rails go, and the 0.9 mm that picked the size

They go on the **20 mm side faces**, rail centre Z = 98, which puts the block at
Z 89.5…106.5 — between the thigh cuff (tops out at 88) and the extrusion's lateral face
(108), entirely inside the carriages' existing envelope. **No dimensional cost at all.**

Getting there took two wrong answers, both from checks that were too small, and both
worth recording because they are the same mistake in different clothes.

**"The side faces clash with the belt."** Wrong for the *blocks*: run A spans
Y 0…`carrA−24` and carriage A's first block starts later, so there is a constant gap at
every pose — the same construction that keeps the ball nut clear. Swept over all 107
poses, block-to-belt overlap is 0.00 cm³ at every rail height tried. But it is right for
the **rail**, which is continuous and therefore does share length with the belt. There is
2.9 mm between the side face at |X| 30 and the belt's tooth tips at 32.86 — it was read as
5.6 mm against a belt drawn 2.7 mm too far out, so the MGN7 fallback is tighter than this
section claimed:

| | Proud of the face | Reaches | vs. the belt |
|---|---|---|---|
| MGN9 rail | 6.5 mm | 36.5 | **0.9 mm into it** |
| **MGN7 rail** | 4.8 mm | 34.8 | clear by 0.8 mm |

**"It clears the cuff."** That test was run on the *anterior* block only. The posterior
side is tighter, because carriage B carried the sprung belt anchor in exactly that corner.
*(This whole guide section is the two-screw history. Both carriages, both MGN7 rails and
the sprung belt anchor are gone — the belt is a closed loop tensioned at the idler now,
and the single gantry runs on mini V-wheels. Kept because the reasoning about mounting
faces and what an interference sweep cannot ask is what led to the current layout.)*
Three changes were needed there and none on the anterior side: the blocks move distal of
the anchor, the anchor moves outboard to X 35.6…44.2, and the tension spring rises to
Z 113 so the block passes under it. Block spacing on B drops to 34 mm as a result, so the
18.0 N·m yaw becomes **529 N per block** against MGN7H's ~1.0 kN dynamic rating — 1.9× on
a peak, not a continuous, load. Carriage A keeps 54 mm and 333 N.

**And a question no interference sweep can ask: can it be bolted on?** The first build
centred the rail on the face at Z = 98 — straight over the V-slot, which `194_layout.py`
cuts at Z 95…101. Every M2 mounting screw would drop into the slot with nothing to grip,
and M2 T-nuts do not exist for a 6 mm slot. The face leaves two solid bands, Z 88…95 and
Z 101…108, each 6.9 mm against the rail's 7 mm. The inboard one puts the block back into
the thigh cuff, so the rail sits on the **outboard** band, centre Z = 104.5, block at
Z 96…113 — which in turn pushed the tension spring up to Z 119 to stay clear of it.

Rail length is cut to what the blocks actually sweep rather than to the extrusion:
**165 mm anterior** (blocks sweep Y 67.0…220.8) and **145 mm posterior** (Y 146.7…280.5).
They differ because the carriages sit at different heights and B's blocks were pushed
distal of the anchor.

This placement also leaves the lateral 60 mm face completely free, which is what the
front-mounted screw layout below would need.

### Why the screws stay at X = ±58

Moving them to the lateral face looks like it saves a lot of width, and it does — but it
spends the wrong axis. Measured against the reference limb:

| Y | Limb radius | Device fore-aft | Proud laterally |
|---|---|---|---|
| 140 | ±72.1 | ±84 | 65.9 mm |
| 200 | ±76.9 | ±84 | 61.1 mm |
| 260 | ±81.8 | ±84 | 56.2 mm |

Fore-aft the fairing clears the limb's own silhouette by only **2–12 mm**; laterally it
stands 56–66 mm proud at the thigh and 86 mm at the knee. Lateral protrusion is what
catches door frames, chair arms and the other leg. Fore-aft is nearly free, because the
thigh is already that wide.

Put the screws on the lateral face and the ball nut has to clear the rail's Z=108 face,
so its axis sits at Z ≥ 122 (SFU1605) or ≥ 126 (SFU1610); the nut reaches Z 136 or 144,
the carriage has to wrap it, and the fairing follows to ~148 or ~156. **Knee protrusion
goes 86 → 96 mm, or 104 mm on 1610.** The return is ~32 mm per side of fore-aft, of
which only ~12 mm was ever outside the limb.

So the current layout is already spending the cheap axis. The mass of the rails lands on
the thigh, which does not swing about the knee, so it costs hip effort rather than the
reflected inertia the screw-lead decision is fighting — the cheap place to spend 219 g.

Numbers: [`scripts/310_guides.py`](scripts/310_guides.py).

---

## Sensing

<div align="center">
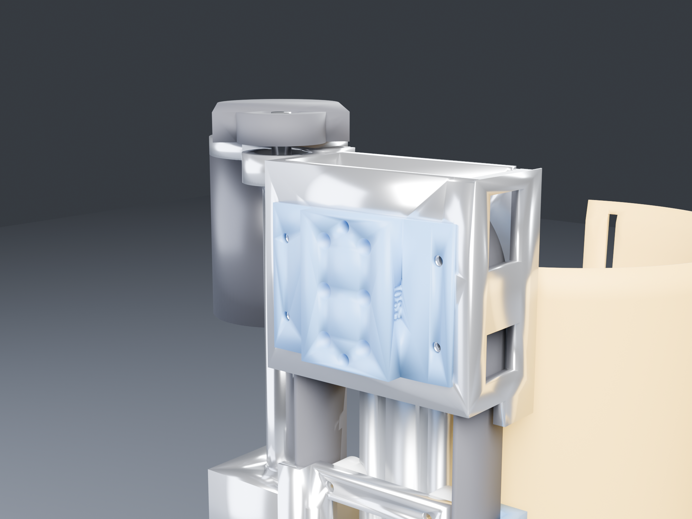
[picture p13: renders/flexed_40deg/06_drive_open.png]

<br><sub>Cycles render · the drive head — idler, gantry and the anterior motor</sub>
</div>

| | |
|---|---|
| **Knee angle** | AS5048A, 14-bit absolute, on a 6 mm diametric magnet sunk into the knee pin's flush counterbore. Absolute at power-on, so **no homing routine** — critical, because the screw turns 6.8 revolutions over the ROM and a motor-side encoder cannot tell which one it is on |
| **Motor** | the drive's onboard AS5047P, 14-bit SPI, commutation and velocity |
| **Tooth-skip detection** | one tooth is 8 mm of belt = **12.9° of knee angle**. Comparing joint angle against motor position makes a skip unmissable — this is the monitor for the failure mode that actually matters, sudden loss of assist mid-stair |
| **Belt tension** | Hall sensor on the **idler carrier's** slotted mount, reading its deflection. A closed loop is tensioned by moving the idler, which retires the sprung belt-end anchor entirely |
| **Endstops** | magnet pockets in the gantry's side wall — hard limits plus auto-calibration of the screw↔knee map |

Full architecture, ODrive configuration, control strategy, regen handling and the bring-up
order: [`docs/ELECTRONICS.md`](docs/ELECTRONICS.md).

The headline: **torque control only, never position** — a position loop fights the patient
whenever their intent differs from the trajectory, which is most of the time. And the
failure mode is benign by construction: a ball screw backdrives at ~89%, so loss of power
leaves a free-swinging passive brace, not a locked leg. That property is worth protecting.

---

## Repository

```
docs/        BOM.md         what to buy, and the screw-lead decision
             PRINT.md       the print list — generated from the STLs, not written by hand
             ASSEMBLY.md    how it goes together, in order, by engraved part number
             ELECTRONICS.md ODrive, ESP32, control, safety, bring-up
             PRIOR_ART.md   what exists already, and why this is not that
model/       KneeExo_v6.FCStd (left) · KneeExo_v6_R.FCStd (right) · *.marks.json
stl/         15 printed parts, left leg        stl_R/  the same 15, right leg
kinematics/  kin_low.json — current pose law; legacy slider-crank kept for reference
renders/     cad/ FreeCAD viewport captures; Cycles stills and animation GIFs  (STALE,
             see Open items — they predate both the drive-cover rework and the engraving)
scripts/     chronological build and verification scripts
tools/       the things that are run repeatedly rather than once
```

**If you are building one:** [`docs/BOM.md`](docs/BOM.md) to order,
[`docs/PRINT.md`](docs/PRINT.md) to print, [`docs/ASSEMBLY.md`](docs/ASSEMBLY.md) to assemble.

Scripts are numbered in the order they were run, so the numbering is history, not structure.
Earlier numbers include all four rejected architectures above. The part of it that is still live:

```
geometry      194_layout → 195_knee → 196_carr → 197_belt → 203_makeroom → 206_fix
              → 210_flush → 217_fairing → 232_covers → 240_nut1610 → 241_fixups → 250_mgn7

the current    393_driveend → 394_lighten_merge → 396_fixes → 397_recladding
build chain    → 398_sidemounts → 399_drivecap → 409_cuffs → 502_interface_build
               run as one headless process by tools/build_headless.py, 3.4 min

marking        412_engrave (place and cut) · 416_unmark (take back out)
               · 702_mirror_marks (reflect the left leg's onto the right)

the pair       701_mirror_build  — left document → right document, Z → −Z
```

**Run the build chain headless, not through the GUI.** The RPC server's 90 s dispatch limit is not a
clean failure: `397` and `409` both exceed it, and on timeout the call returns an error *while the
work carries on in the background*, leaving a half-built document the next stage reads as finished.
Every half-applied state in this project came from that. `freecadcmd` has no such limit.

| Tool | What it is for |
|---|---|
| [`tools/build_headless.py`](tools/build_headless.py) | the whole build chain in one headless process, un-posing first |
| [`tools/sweep.py`](tools/sweep.py) | the 107-pose interference sweep, 10 shards, 2.5 min |
| [`tools/unpose.py`](tools/unpose.py) | clear a leftover animation pose — the one corruption that passes every other check |
| [`tools/markframe.py`](tools/markframe.py), [`tools/marktool.py`](tools/marktool.py) | which way a part number points, and what it is cut with |
| [`tools/readmark.py`](tools/readmark.py) | print each mark as ASCII, as the reader sees it |
| [`tools/restyle.py`](tools/restyle.py) | put colours and visibility back after a headless rebuild |
| [`tools/snapshot.py`](tools/snapshot.py) | copy the documents, registries and STLs into the repository |
| [`tools/fcsend.py`](tools/fcsend.py) | send Python to the running GUI instance (XML-RPC, port 9880) |

[`scripts/fc.py`](scripts/fc.py) is the older FreeCAD client; `tools/fcsend.py` supersedes it and
adds the pose check.

### Images

Two kinds, and the difference matters when you are reading a shape off one of them:

> [!NOTE]
> **Every image here records which geometry it shows**, in
> [`renders/manifest.json`](renders/manifest.json), and
> [`902_doc_audit.py`](scripts/902_doc_audit.py) fails if any of them disagrees with the model.
>
> This exists because six renders of a boxy `P22` and non-conical cuffs sat at the top of this
> README for weeks after both were redesigned, and **nothing could have caught it**: the link
> checker reads markdown links and these are HTML `<img>` tags, and in any case a file that exists
> is not a file that is current. Timestamps cannot answer it either — git does not preserve mtimes,
> so every file in a fresh clone is the same age — and hashing the `.FCStd` cannot, because saving
> it changes the bytes whether or not anything moved. So the fingerprint
> ([`tools/fingerprint.py`](tools/fingerprint.py)) hashes the thing a picture actually depends on:
> every part's name and volume, to a thousandth of a cm³. Move a part and it changes; re-save, or
> rebuild from the same scripts, and it does not.

**FreeCAD viewport captures** ([`renders/cad/`](renders/cad)) are the model itself — flat
shading, edge lines, orthographic wherever the view is a technical one, and the tan
reference limb shown at 75% transparency. Nothing is retouched and nothing is
approximated. Produced by [`scripts/223_cad_shots.py`](scripts/223_cad_shots.py), then
autocropped by [`scripts/crop_cad.py`](scripts/crop_cad.py). All **eleven** are scripted and were
regenerated against the current model; four of them (`cuff_thigh`, `cuff_shank`,
`drive_antlat_clad`, `drive_antlat_open`) had been framed by hand in a session and existed in no
script, which is why they were the oldest images in the set — the same failure as the Cycles stills
below, and as `vs_leg()` and `SUFFIX` in the build scripts.

That script also used to end with `pose(30.0)`, leaving the document flexed. Nothing in it saves, so
it looked harmless; the pose then waited in the session until the next build script called
`doc.save()` and baked it in. It ends at the design pose now.

Three things that script has to get right, all of which caught me out first time:

- **`REF_Shank` belongs with the shank.** `vlow.py` has always posed it, so the clash
  sweep was never blind — but `221_render_export.py` and `222_anim_export.py` both omitted
  it. Invisible while the reference limb was hidden; wrong the instant it was shown, with
  the limb standing straight while the device flexed.
- **No standard FreeCAD view stands the device up**, because the limb axis is +Y and
  anterior is +Z. Camera orientation maps the camera frame into world and the camera looks
  down its own −Z with +Y up, so *identity* is the frontal view with the limb vertical.
- **The MCP's `get_active_screenshot` forces a standard view**, silently discarding any
  custom camera. Use the view's own `saveImage` instead.

**Cycles renders** ([`renders/flexed_40deg/`](renders/flexed_40deg),
[`renders/extended_0deg/`](renders/extended_0deg), [`renders/anim/`](renders/anim)) are
presentation: **512 samples**, AgX medium-high contrast, f/11. Materials are keyed off the `MAT__`
filename prefix [`221_render_export.py`](scripts/221_render_export.py) writes into each filename.

> [!IMPORTANT]
> **The eight-shot sets are stale, and seven of the eight cannot be reproduced.** They predate the
> drive-cover rework, the conical cuffs and the engraving. Worse, no script in this repository
> produced them: the eight camera angles were framed by hand in a Blender session, so they exist
> nowhere — not in a file, not in a comment, not recoverable from the images. The only camera
> direction the repository records is `(0.62, −0.76, 0.20)`, in `b3_frame.py` and again in
> `b5_reframe.py` and `anim_common.py`.
>
> So [`b6_stills.py`](scripts/b6_stills.py) renders **that** direction — clad and open, hero and
> knee, per pose — and nothing else. Guessing the other seven would have been easy and wrong: a
> render is a claim about what the thing looks like, and eight invented viewpoints replacing eight
> stale ones is the same problem with a newer timestamp.
>
> Two other things were broken in that pipeline and are now fixed. `b1_scene.py` keyed materials off
> a hand-written table of bare part names — including `P2b_RodClevisBlock` and `P4_Rod_8mm`, both
> deleted with the rod linkage — so feeding it the current export died on the first file with
> `KeyError: 'ALUM__A7_DriveBox'`. It now reads the `MAT__` prefix, which is what the paragraph above
> always claimed it did. And its source directory was hardcoded to the animation export, so the
> still export could not be fed to it without editing the file; `KX_SRC` chooses now.

Animation: also Cycles, 96 samples, 32 frames on `θ = 52 − 52·cos(2πi/32)` — smooth, and it loops
with no duplicated end frame because the law already returns to its start. The camera is framed
**once**, on the widest pose, and then held: refit per frame and the bounding box moves, so the whole
device appears to breathe instead of the shank swinging about a stationary knee.

[`b7_anim.py`](scripts/b7_anim.py) replaces `b4_anim.py`, which animated an architecture that no
longer exists — it reads a September `kinematics.json` carrying `rod_len`, `Dx/Dy` and `phi`, and
keyframes a rod end, a clevis and a slider-crank through them. The rod linkage became a belt over a
capstan; `b4`'s part lists still name `P2b_RodClevisBlock` and `P4_Rod_8mm` and omit every piece of
cladding added since, so the fairings, the drive wall, the three mounts and both interface bosses
would have stood still while the leg bent.

What replaced all of it is two expressions, because that is what the mechanism now is: the shank side
rotates by θ about the knee axis, and the gantry slides by `(A0 − R·θ) − A0` along the limb. Both are
the same lines `406_coverage.py` and `601_verify_fast.py` use, and the **part lists are 601's** — so a
part added to the interference sweep is animated too, instead of drifting in a sixth hand-maintained
pose list. That drift is the trap two sections below: a part can be in a check's list and never be
posed.

```bash
python scripts/300_drivetrain.py               # every drivetrain number, no FreeCAD needed
python scripts/fc.py run scripts/194_layout.py # build geometry
python scripts/fc.py run scripts/223_cad_shots.py &&   python scripts/crop_cad.py C:/Users/Josh/KneeExo_render/cad
```

---

## As a module of a full exoskeleton

The question this was built to answer is one knee. The question it will be asked next is what
a leg looks like, so [`500_as_a_module.py`](scripts/500_as_a_module.py) puts numbers on it
before any more of the design hardens around a single joint.

**A full exo cannot be eight of these.** The knee is the *smallest* of the four lower-limb
joint types — the ankle wants 38 N·m at 30 % assist against the knee's 25, and 3.5× the peak
power. Eight joints built like this one is 30.2 kg on the legs, which at published penalties
for added limb mass is a **106 % metabolic cost against a 30 % assist budget**: 3.5× upside
down. Even a perfect exo returning every newton-metre it promises would cost more than it
gives. The ways out are architectural — load to ground, remote actuation at the pelvis, or
assist fewer joints.

**Every module usable alone *or* federated** is a stronger requirement than "modular", and it
cuts against that mass. A module that works alone carries its own reaction path, controller,
safety interlock and power — exactly what makes eight unwearable. So the architecture is
modules that **shed** when they federate: local battery, second cuff, standalone MCU, e-stop
link, its own loom — **1252 g, 33 % of the module**. A federated knee is 2.53 kg against 3.78.
Shedding makes the system possible; it does not make it light.

**The cuff stops being part of a module.** A hip module and a knee module both clamp the
thigh. Self-contained they bring a cuff each — two shells fighting for the same 429 mm of
limb, each applying its own roll torque. Federated they share one, which makes the cuff a
component in its own right and means the thing to standardise is its *mounting interface*,
not its shape.

**Room to interconnect is tighter than it looks.** For a 1.75 m subject the hip joint centre
is 429 mm above the knee and the ankle 430 below, while this module reaches Y +334 and −350 —
so **95 mm at the top and 80 mm at the bottom**, and into those must fit the next joint's
bearing, its structure and the splice. The drive end is the tight one, and it already spent
its reach allowance moving the motor anterior.

**A 1 kHz host loop over one CAN bus does not fit** — 8 nodes × 2 frames × 108 bits is 173 %
of a 1 Mbit/s bus. Not a problem, but it dictates the architecture: the drives close current
and velocity locally and the bus carries setpoints at ~200 Hz (35 %); if something ever needs
kilohertz, split left and right legs onto two buses rather than raising the rate.

### The KX-1 interface, fitted at both ends

[`501_interface.py`](scripts/501_interface.py) sizes it and
[`502_interface_build.py`](scripts/502_interface_build.py) builds it. The trap was sizing for
today's load: standalone it only ever relieves a cuff, 148 N. Federated with a load-to-ground
structure the same joint carries **1472 N**. Sized for the first number it is scrap the day
the second module arrives.

**Bearing sizes it, not tension and not the bolts.** 6 × M5 at class 8.8 is 36 kN of capacity
against a 2943 N design load — never the limit. Bearing on a 5 mm hole in a printed boss is,
and 4 bolts fails at every sensible thickness while 6 passes at 10 mm. Bolt count is the one
thing in a mating pattern that cannot change later without changing both halves, so it is
worth having found now.

| | |
|---|---|
| face | 56 × 40, 10 mm boss |
| bolts | 6 × M5 at face-X −18/0/+18 by face-Y ±9 |
| dowels | 2 × ⌀5 H7 at face-X ±24 — two pins fully constrain in plane, and this interface is what sets where the joint axis lands relative to the patient's |
| frame | face-X along the module's +Y, normal pointing out |

The face points **laterally, not axially**: a lap joint costs none of the 95 mm budget and
carries bending without relying on bolt tension, which an end-butt flange cannot. `P30` sits
on `A7`'s top plate and pierces the drive shell through a port it then fills — coverage stays
at 0 of 187 rays. It needed wings to reach solid metal, because `394`'s lightening windows
leave `A7` solid only at |X| 32…40.

Four placements were wrong before one was right, every one caught by a **per-hole** engagement
check rather than an aggregate one — the first layout put two of four bolts into a lightening
window and "0.13 cm³ removed" looked entirely plausible.

### A part can be in a check's list and never be posed

`P31_InterfaceDist` was added to the interference sweep's part list and to the coverage test's
blocker list, and it passed both. It was also sitting at identity placement while the shank
rotated — **88 mm from the socket it bolts to**. It was blocking coverage rays from a position
it does not occupy, and it was drawn detached from the leg in every CAD shot.

The cause is that `406_coverage.py`'s `pose()` keeps a hardcoded shank tuple that is *separate*
from its `BLOCK` list, so a part can be an occluder and never be moved. The same split exists
in `220`, `221`, `222`, `223` and `395` — five pose lists and five part lists, maintained by
hand. Adding a part means touching both halves of all of them, and nothing complains if you
miss one.

Worth knowing because every clean result this repo produces depends on the parts being where
the checks think they are, and that is the one thing none of the checks test.

## Building the pair

The model is the **LEFT** leg. `+Z` is lateral and the whole device lives at `+Z`, so nothing
straddles the sagittal plane and every printed part is chiral. The right leg is a reflection,
`Z -> -Z`, built into its own document by
[`scripts/701_mirror_build.py`](scripts/701_mirror_build.py):
`KneeExo_v6.FCStd` (left) and `KneeExo_v6_R.FCStd` (right), 37 solids each.

### Sourceability is a design constraint, not a preference

This is meant to be reproducible by someone who is not me, somewhere else, later. That makes **“can a stranger buy this?”** a hard requirement on anything in the critical path, and it has teeth: a bought HTD-8M 28T × 32 aluminium pulley was specced for the capstan and the idler for about a day. It was genuinely better — it retires [`421`](scripts/421_pulley_teeth.py)'s unproven tooth profile on the highest-loaded pulley in the machine, and lets the bearings press into metal instead of bonding into PETG. It was dropped anyway, because “10 available from one eBay seller” is a window, not a part.

Three lines that looked like blockers are not: the **battery** is being broken down and re-laid out around an off-the-shelf BMS, which turns it from one specific A123 module into a 12S LiFePO4 pack anyone can build; the **XDRIVE MINI** is a popular clone; and the **HTD-8M belt** was cheap open-loop stock. What the repack has to preserve is in BOM B1, because the electronics is sized against the pack's parameters and not its part number.

The rule that came out of it: **everything on the critical path is either printed, or a catalogue number anyone can order.** A 6904 is a bike-shop bearing. ⌀20 linear shaft is stocked by every 3D-printer supplier. A 29T HTD-8M pulley in a specific width and bore is not, so it is printed — which puts `TEST_ToothCoupon` on the critical path for real, since the printed tooth form is `421`'s approximation of an unpublished curve and the coupon is the only thing that can qualify it.

Chasing that constraint also found a mistake. [`457`](scripts/457_knee_bearings.py) chose a 6001 for the knee on the grounds that “it costs no new part number” — and that commonality argument cost the shaft three quarters of its section. The printed capstan takes a **6904** with 14.3 mm of wall to spare, so the bigger bearing was available all along: **cantilever 94 → 20 MPa**, tilt 52 → 69 N·m, and the bond area 418 cares about 704 → 1046 mm². Strictly better, and no less sourceable than what it replaces.

### v8, and why it is one script rather than a new lineage

`KneeExo_v8.FCStd` is **v6-left plus [`scripts/459_v8_drivetrain.py`](scripts/459_v8_drivetrain.py)**, the same arrangement [`419_knee_coaxial.py`](scripts/419_knee_coaxial.py) used for its v7. v6 is ~300 scripts run in an order recorded nowhere; v8 is v6 and one file, reproducible in seconds, and that file says what changed and why. Left leg only for now.

What it carries that v6 does not: the **drivetrain the bench actually has**. A 200 mm SFU1605 set arrived — 5 mm lead, BK/BF12 ends, flanged nut, DSG16H housing — where the model was drawn around an SFU1610 at a 10 mm lead with invented ⌀8 journals. So the screw becomes ⌀10 × 11 floating / ⌀12 × 25 fixed with 135 mm of thread between; the link pulleys become **38T:20T** because 5 mm doubles the screw's own reduction and 32T would leave the leg feeling 87% heavier unpowered; the belt is an exact **54T** at the 60.83 mm centres; the screw's upper bearing goes from a 608 to a **6001** because ⌀8 was never real; the pod is bored out to clear a 38T belt run; and **`P32_ScrewFoot` exists at last** — [`445_screw_foot.py`](scripts/445_screw_foot.py) went looking for something to bolt the screw's lower bearing to and found “a yoke corner, a belt and cladding. No mount.”

**The pod had to be rebuilt around the 38T, and that was the hard part of this build.** The belt's back sits at r 33.47 from the motor axis (tip 29.67 plus the belt's own 3.8) and `P25_MotorNacelle`'s bore was r 29.7 — **6.9 cm³ of belt inside the wall**. [`446_sfu1605_set.py`](scripts/446_sfu1605_set.py) predicted 0.2 mm of this from the pulley's *pitch* radius and was out by a factor of twenty, never having added the belt's thickness. Three things had to be right to fix it:

* the bay is **grown before it is cut**. P25's dome sits ON the motor axis, so a relief bore amputates the end of the part rather than thinning a wall — which is exactly what the first attempt did, and the discarded “lose fragment” was the dome.
* the relief is **the belt's own stadium, not a cylinder**. A cylinder round the motor leaves the straight runs buried, 0.95 cm³ of them, 60.83 mm away at the screw pulley.
* the grown bay then wraps the **screw**, which needs its own running clearance bored back out of it.

P25 goes 97.7 → 103.9 cm³ for a belt bay that actually holds the belt. The relief now runs a **whole-section check** before cutting anything: if a bore would take more than 95% of the material in any 4 mm slab, it refuses and says so, because that is not a wall.

**And the motor pod has a 77° cliff on its leading edge, found but not yet fixed.** The complaint was that it hangs off separately; measuring it found that it does not stick out — everything above the knee lies between r 145 and r 161 and the cladding is only 3–7 mm proud of its contents. What it does is **start abruptly**: slicing by sector, the posterior-lateral quarter goes from r 136.7 at Y 200 to r 158.0 at Y 205 — **21.3 mm in 5 mm, a 77° face pointing down the leg**, which is what catches on a chair or a duvet. [`464_thigh_blend.py`](scripts/464_thigh_blend.py) measures it and can build a ramp, but **the ramp it builds is a lofted pie wedge with flat radial sides and reads as a fin stuck on the pod rather than a fairing grown out of it.** It is reverted; the finding and the test stay, so whoever draws a proper surface blend has a number to beat. [`460_v8_claims.py`](scripts/460_v8_claims.py) asserts the 77° defect deliberately.

Three things that did *not* turn out to be true, each found by measuring after assuming:

* **merging the cladding saves no mass.** P21, P22 and P25 have **zero** mutual overlap — fusing them recovers 0.00 cm³. There are no doubled walls to delete.
* **the cladding is 230 g, not 531.** The solid volume is 418 cm³ but it prints at two walls and low infill; I had applied solid PETG density to a part that is mostly air.
* **centring the screw on the rail makes the carriage WORSE, not better.** [`462`](scripts/462_bevel_at_idler.py) recommended it on the grounds that it makes the nut's reach symmetric. It does not: the carriage reaches from the nut to the one belt strand it clamps, at X −37.3. From the screw's X −62 that is 24.7 mm; from X 0 it would be 37.3. The recommendation is retracted in the script.

What it deliberately does **not** carry, because the dimensions do not exist yet: `P3_GantryPlate` redrawn for the flanged nut and its housing, the main belt's tunnel lengthened from 5 grooves to 8 for an open-ended belt, and the joint encoder's mounting — which [`457_knee_bearings.py`](scripts/457_knee_bearings.py) invalidated by making the knee rod static, and whose magnet carrier, axial retention and sensor bracket have to be designed as one piece.

Separate documents, not more objects in one, for two reasons: every verification script works on
"each Part::Feature in the document", so doubling the objects would double every sweep and halve
what the results mean; and interference, coverage and contact pressure are all invariant under
reflection, so the right leg does **not** need the 107-pose sweep repeated. Keeping it separate
states that argument instead of burying it.

What does not mirror is the **ball screw**. Reflecting an assembly reflects its threads, so a
literal mirror wants a left-hand SFU1610 — a special order at a premium, already priced and
rejected in [`370_no_lh_screw.py`](scripts/370_no_lh_screw.py). The screw is not a structural
mirror of anything; it is a rotary-to-linear converter between two parts that *are* mirrored.
Keep the RH screw on both legs and the only consequence is a sign:

| | +motor rotation | nut travels | knee |
|---|---|---|---|
| left | + | distal | **extends** |
| right | + | distal | **flexes** |

One constant, in one place — the joint direction in firmware. The trap is doing nothing and
assuming symmetry: a right leg with the left leg's sign drives the knee the wrong way under a
28.2 N·m assist, which is not a subtle failure. See
[`700_handedness.py`](scripts/700_handedness.py).

For a pair the printed and fabricated parts double but do **not** repeat — they are new part
numbers, not more of the same: 15 L + 15 R printed (2.5 kg of filament), 2 L + 2 R aluminium
(956 g). Everything symmetric is shared: extrusion, belts, pulleys, motors, drive, V-wheels,
bearings, fasteners, neoprene sleeves, webbing.

### The part numbers carry the leg

Each printed part is engraved with its number **and its leg letter** — `P5L` and `P5R` — 0.8 mm
recessed, on a face that is hidden once assembled, by
[`412_engrave.py`](scripts/412_engrave.py). The pair is the reason the letter is there at all:
the two cuffs, the two drive-shell halves and the three fairing mounts are already hard to tell
apart on the bed, and with two legs in the same print queue there are thirty parts, not fifteen.

Three things this costs, all of them paid rather than argued away:

- **A mirrored mark reads backwards**, so the right leg cannot inherit the left's engraving. The
  mirror is taken from a fully *un-engraved* left leg, and each leg is then engraved through the
  same code with its own letter. Four parts live outside the `393…409` rebuild chain and keep
  their marks forever, so `412` also has a **fill** mode that rebuilds the original cutting tool
  and fuses it back, verified by probing the skin before and after (59% solid -> 100%).
- **One more character needs more room.** `P24L` is 5.5 mm longer than `P24` at 8 mm, which was
  enough that the placement search found no smooth patch at all on two parts. The cap-height
  ladder now steps 8 -> 5 -> 4 mm; `P24` sits at 4 mm and `P1_KneeYoke` needs an explicit site,
  because its surface satisfies no automatic search.
- **Where every mark went is now recorded** next to the document, in `<doc>.marks.json`, and the
  visibility check reads it. It used to read a table copied by hand from `412`'s printed output,
  and adding the leg letter moved five of the fourteen marks — a hand-copied table would have
  been testing bare surface and reporting it covered.

### Nothing was reading the part numbers

Twelve of the fourteen marks were cut as **mirror images**, and every check in this repository
passed them. `412` verified the cut removed a plausible volume; `413` verified no ray escapes from
the mark's surface; `411` verified the mesh. None of them asks what the glyphs *say*.

The cause was duplication. `412` built the text frame inline, four times, once per mark style — and
three of the four were left-handed. A glyph reads forwards only when the layout's reading direction
is the reader's right hand, and for a reader standing on the open side of the surface looking along
`into` (the direction the material lies), with their head up along `up`, that is

    right = into × up

Get the sign wrong and the mark is still 0.8 mm deep, still on a hidden face, still one clean
solid, and still unreadable. It cost a full re-engraving of both legs.

Three things came out of it, and they are the shape of the fix rather than the fix itself:

- [`tools/markframe.py`](tools/markframe.py) is the single authority for which way a mark points,
  with the rule stated once. `412`, `416` and `702` all call it, so they cannot disagree again.
  It also carries a `legacy` flag that reproduces the old left-handed frames, for the one job that
  needs them: *filling* a mark that was cut with them.
- [`tools/marktool.py`](tools/marktool.py) holds the shared tool-building — the text, the 6% tool
  inflation that avoids fusing across coincident faces, the `removeSplitter`-then-raw-fuse
  fallback, the skin probe. Same reason.
- [`tools/readmark.py`](tools/readmark.py) prints each mark as ASCII, sampled from the reader's own
  viewpoint, so "does it read forwards" is now a check and not an assumption. No renderer, no
  screenshot: sample 0.4 mm inside the material and print `#` where material remains.

Removing the bad marks was its own problem. [`416_unmark.py`](scripts/416_unmark.py) rebuilds each
cutting tool from the registry and fuses it back, verified by probing the skin before and after
(59% solid → 100%). It worked on 13 of 14. The shank fairing refused every variant — at tool
inflation 1.0 the volume came back exactly right and the solid was still broken — so it was
rebuilt blank from its own generator instead, which meant making `217_fairing.py` and
`232_covers.py` run headless. A part that resists booleans is better regenerated than repaired.
(That part is gone now; the lesson is not.)

Two more of the same kind, found while mirroring the right leg. `P31_InterfaceDist`'s mark
station was **15 mm above the part** — the socket's top came down to Z 98 and the station still
said 123 — so 412 cut nothing, 413 found nothing visible, `readmark` rendered the site as solid,
and the part went out unnumbered on **both** legs. And [`702_mirror_marks.py`](scripts/702_mirror_marks.py)
refused two of sixteen because its "is this already engraved" gate was an absolute skin
threshold: P22's reflected site reads 79% against a threshold of 80%, so it tried to fill glyphs
that had already been filled, added 0.000 cm³, and skipped the part instead of cutting it. Both
checks passed for years by having nothing to find.

### What is in the repository, and what the repository is missing

`model/` holds both documents and both mark registries; `stl/` is the left leg and `stl_R/` the
right. They are COPIES — the working files live at `C:/Users/Josh/KneeExo_v6*.FCStd` because ~300
scripts hardcode that path — so [`tools/snapshot.py`](tools/snapshot.py) copies them in and, run
without `--write`, says what has drifted. It is worth running before every commit: after both legs
were re-engraved, `model/` and `stl/` still held the previous commit's parts, the ones whose
numbers were mirror images, and nothing said so.

The `<doc>.marks.json` registries are tracked because they are inputs, not logs. `702` reads the
left leg's to place the right leg's marks, `413` reads it to know what to test, `416` reads it to
take a mark back out, and `readmark` reads it to print what each one says.

The binary `.FCStd` is tracked too, in a repository whose whole point is that the scripts are the
source, because **the document is not reproducible from the scripts alone** — it is ~300 of them run
in an order recorded nowhere, over weeks. `tools/build_headless.py` reproduces the last eight
stages in 3.4 minutes; everything before that exists only in the file. That is a real gap, not a
convention, and it is on the open-items list.

### Two documents means two of everything downstream

STLs export to a directory named after the document (`KneeExo_v6_STL`, `KneeExo_v6_R_STL`), one
per leg. The part object names are identical in both files, so a single shared folder would
quietly leave one leg's STLs under names that look like a complete set.

## Open items

- ~~**The knee bushings have nowhere to sit**~~ — **fixed, with a bearing instead of a bushing.**
  BOM K3 asked for two M12 flanged bushings; a ⌀12-bore bushing needs a 14–16 mm seat and the knee
  axis had only ⌀12.3 pin clearance, so they had never been modelled and a steel pin ran directly in
  printed PETG. A plain bearing was the wrong part anyway: at 764 N it puts a **0.69 N·m friction
  deadband** at the hinge against **0.007 N·m** for a sealed ball — a stiff hinge on a limb that is
  supposed to swing freely when the device is off, which is the property the whole 14.5:1 drivetrain
  was sized around. [`418_knee_bearing.py`](scripts/418_knee_bearing.py) seats a **6001** (28 × 12 × 8,
  SF 3.1) in `P1_KneeYoke`, where the hub straddles it so the load is symmetric and it sees no cocking
  moment — the one place it could go, since the yoke is solid out to r 43–55 and the pulley rim is at
  r 35.5, so no bolt circle could ever have passed between two hub halves. Bonded, not pressed: PETG
  creeps and a press fit is gone in months. The remaining ⌀12.3 bores are in the hub, which the pin's
  collars **clamp** — nothing printed turns against steel any more, and
  [`417_fastener_audit.py`](scripts/417_fastener_audit.py) now checks that as a standing question.

- ~~**A better knee exists and is not built.**~~ — **built, in a second form.** [`457_knee_bearings.py`](scripts/457_knee_bearings.py) moved the joint into the belt plane on both legs, using **two 6001s at Z 96…104 and Z 118…126** rather than 419's single 6808: a lone ring reacts tilt only inside its own race width, order 10 N·m, where a pair reacts it as a couple over 22 mm and takes ~52. 419 had weighed a two-bearing fork and rejected it on "two ⌀95 seats that must be coaxial, in printed parts" — true of 6815s, ordinary of ⌀28. P2a went 148.1 → 134.2 cm³ and the pin, its collars, the hub's lugs and the clamp stack are all gone. **419 still has what this gave up**: a hollow ⌀40 centre for cabling, and 47 g. The original note follows. The pin-and-6001 joint is sound, but the bearing sits
  beside the belt rather than in it, and the pin still passes through the hub's plastic (clamped, so
  it does not rub — but it is three parts and a clamp stack where one bearing would do).
  [`419_knee_coaxial.py`](scripts/419_knee_coaxial.py) models the alternative in its own document:
  a **6808-2RS (40 × 52 × 7) nested inside the toothed ring**, in the plane of the belt. The tooth
  root circle is ⌀65.6 (⌀64.3 before 421 corrected the tip radius), so a bearing under about
  ⌀63 fits inside it with 6.3 mm of rim — and the belt
  pull then passes straight through the bearing plane instead of 20 mm to one side of it, which on a
  single 6815 beside the teeth would have been 764 N × 0.020 = **15.3 N·m of moment on one raceway**.
  It passes the 107-pose sweep, keeps the full belt land, is **47 g lighter**, and opens a **⌀20 hole
  straight through the knee** for cabling — which is worth more to the exoskeleton than to this
  device.

  Not built because it still needs coverage, printability, re-engraving and the mirror, and because
  `v6` is the one with teeth in it: [`421_pulley_teeth.py`](scripts/421_pulley_teeth.py) would have
  to be run against that document too, and `v7`'s tooth root circle is exactly what its nested
  bearing has to fit inside. Two things it taught that the sketch did not: cutting the stub clearance
  **split the pulley in two**, since the 165 mm shank plate's only path to the rim ran up the middle
  where the stub now goes (so the shank has to wrap the stub — which is what "the bearing is the only
  thing crossing the joint" looks like drawn); and a fuse needs real interference, because two
  attempts left 0.1 and 0.05 mm gaps and the solids merely touched.
- **The three fairing mounts are not anchored where the documents say.** BOM S2b's neighbours and
  ASSEMBLY step 22 both describe `P23a/b/c` going "into the extrusion's posterior side slot at
  Y 88, 124 and 160 — one M5 each, on rubber grommets, isolating rather than rigid". Each mount
  does have exactly one M5, and it is **vertical at X 25** — outside the rail, which spans
  X −20…20, so it cannot enter the posterior slot at any Z. What it actually passes through is
  `P1_KneeYoke` (mounts a and b) and up into `P21_ShellAnterior`. So the canopy's three mounts are
  tied to the yoke and the canopy, not to the rail, and the grommet isolation the documents
  describe is not in the model.
  **This is a design decision, not a defect to patch**: anchoring to the rail's posterior slot and
  anchoring to the yoke are different answers about how vibration reaches the shell, and the
  second one leaves `P23c` at Y 160 with no yoke under it (the yoke ends at Y 124). Decide which,
  then draw it. Found by [`420_mockup_audit.py`](scripts/420_mockup_audit.py)'s question applied
  to a part the table had already passed on "a bolt into the extrusion slot ≥ 1".

- ~~**Four printed parts have no fastener holes drawn**~~ — **fixed.** `P3_GantryPlate_Printed`
  carried the ball nut and rode on four V-wheels while containing exactly two cylinders, both
  ball-screw clearance: the wheels and the nut were separate solids that happened to sit in the
  right place, and nothing bolted to anything. `P20_KneeShroud`, `P22_DriveCap` and
  `P25_MotorNacelle` were the same, though they are cladding rather than structure. No diameter
  table could notice this, because a table only reports what is there;
  [`417_fastener_audit.py`](scripts/417_fastener_audit.py) asks the absence question too, and
  [`420_mockup_audit.py`](scripts/420_mockup_audit.py) asks it per feature. The gantry now has its
  four M5 wheel bolts at |X| 23.36, two M5 set screws locking the flangeless nut against rotation,
  and a five-tooth belt land; the three cladding panels have two M4 each into the structure they
  cover. **The cladding fixings are a decision, not a calculation** — bolts were chosen because
  they are serviceable, and clips or bonding would both work.
- ~~**The two fabricated aluminium parts**~~ — **gone; both print.** `S2d` and `S2e` were the only
  parts in this build needing a workshop, and neither was ever sized by load:
  [`400_bracket_stress.py`](scripts/400_bracket_stress.py) had the bracket 50× overbuilt at 4.3 MPa
  against aluminium's 240. In PETG the governing rule is creep and bearing, not yield, and
  [`802_no_metal.py`](scripts/802_no_metal.py) puts 6 mm plates at 9.8 MPa with the idler bearings
  seated in them at 5.9 — where a bare 10 mm axle through plastic would be 15.2 and bed in.
  Printing both **saves 241 g**, because 1.27 g/cm³ against 2.70 beats the extra section. Every
  metal part left in the build is bought: extrusion, screw, nut, bearings, pulleys, motor, fasteners.
- **No FEA.** Hand calculations only.
- **The document is not rebuildable from the scripts.** `tools/build_headless.py` reproduces the
  last eight stages; the ~290 before them ran in an order that exists nowhere, so `model/*.FCStd`
  is tracked as source rather than as an artifact. Whether that is worth unpicking depends on
  whether this design gets built a second time.
- ~~**Screw lead unsettled**~~ — **settled and built.** 10 mm, and the CAD nut is now the OD 36
  SFU1610 flangeless (`A2b_BallNut_SFU1610`, 36 × 42 × 36 in the model), on the axis at X = −62.
- **Printed mass ~1.65 kg per leg**, 3.3 kg for the pair, over 17 parts and about 103 printer-hours
  each — see [`docs/PRINT.md`](docs/PRINT.md), which is generated from the STLs rather than written
  by hand. It was 1.38 kg over 15 parts until [`802_no_metal.py`](scripts/802_no_metal.py) printed
  the gantry plate and the drive bracket, which ADDS 270 g of filament here and removes 511 g of
  aluminium from the machine. Before that it read 1.59 kg, because it counted two parts that no
  longer exist: `P3b_CarriageB` and `P11_SprungAnchor` went with the second ball screw. The
  remaining candidates for a diet are `P21_FairingThigh` (165 cm³), `P5_ThighCuff` (161 cm³),
  `P22_DriveCap` (152 cm³), `A7_DriveBracket_Idler` (137 cm³),
  `P1_KneeYoke` (134 cm³) and `P2a_KneeHub_Pulley29T` (134 cm³ — **it was 148 until
  [`457_knee_bearings.py`](scripts/457_knee_bearings.py) deleted the 44 mm of reach it only
  had because the bearing sat beside the belt instead of in it**).
- ~~**Carriage guides are sliding, not rolling**~~ — **changed.** Four **mini** V-wheels
  (`P10a-d_VWheel_Mini`, OD 15.23) on the extrusion's corners, 70 mm apart in Y. A solid wheel
  reaches |X| 37.6, inside the belt's backing at 36.24…38.46; a mini reaches 31.0 and clears the
  belt's tooth tips at 32.86 by 1.86 mm. [`396_fixes.py`](scripts/396_fixes.py)
- **The motor sits at the hip**, where the reference limb model ends (Y = 300). Its 100 mm
  clearance is measured against nothing and needs a fitting check on the patient.
- **Belt tooth-shear figures come from continuous-duty power ratings**, which carry fatigue
  derating for high-speed running. A slow capstan can run closer to the cord limit — check
  against the actual belt's data before committing.
- **Acoustics are unmeasured.** Ball nut recirculation (~290 Hz) is the likely dominant
  source and the fairing is the likely radiator, since it hangs off a rigid spine into the
  rail. Analysis and mitigations in [`docs/ELECTRONICS.md`](docs/ELECTRONICS.md) §9; bench
  measurement is now step 2 of bring-up. The one-screw rebuild changed the guide answer: a
  20×60 fouls the belt with any wheel, but the 20×40 it now uses clears a **mini** V-wheel
  by 4.6 mm. Not a solid one — a V groove seats the corner apex at the bottom of the groove,
  so the wheel centre stands off along the 45° bisector and a solid wheel still fouls by
  2.0 mm. `320_rail_section.py` put the centre *on* the corner and so claimed both fit;
  corrected there and in [`396_fixes.py`](scripts/396_fixes.py). The open question is the
  mini wheel's load rating against the 362 N per wheel the yaw couple puts on it — if that
  is tight, MGN7 on the same 20×40's side faces has 7.6 mm of clearance and 2.8× margin,
  where on the 20×60 it had 0.8 mm. **OpenBuilds publishes no load rating at all** — only
  Delrin's 63 MPa compressive strength — so
  [`401_vwheel_load.py`](scripts/401_vwheel_load.py) computes it: at the 50 mm wheel
  spacing first built, the Hertzian contact on each 45° flank peaks at **107 MPa against a
  ~101 MPa yield onset**, meaning the wheel flattens and the gantry develops play at every
  torque reversal. Widening to **70 mm** brings it to 91 MPa — an 11% margin, thin but the
  most available, since 80 mm would push the idler proximal and proximal length is the one
  budget with nothing left in it. Costs 5 mm of rail and ~24 g.
- **Nothing checks assembly.** Every verification in this repository is interference —
  "do two solids overlap". Nothing asks whether a part can be *fastened*, whether a tool
  can reach a screw, or what order things go together in. That gap is how the rails came
  to be modelled directly over the V-slot, where their mounting screws would have had
  nothing to bite.
- **Reflected inertia is the real weakness**, not mass or torque density. At 23.2 : 1 this
  design sits at the top of the quasi-direct-drive band the field uses (8–36 : 1), and
  0.167 kg·m² costs 5–21 N·m during swing depending on acceleration. The fix is
  **SFU1616 — 16 mm lead, 14.5 : 1** — which gives 0.065 kg·m², **0.22× the limb**, on the
  motors already owned, and keeps the OD 36 nut the carriage is already bored for.
  Counter-intuitively a *bigger* motor is worse: torque goes as R²L and inertia as mR², so
  buying torque with diameter buys inertia back. A 6384 on an SFU1620 does reach 0.17×,
  but that last 4% of the limb's inertia costs 49.6 A against 39.7 A — more than the drives
  on hand will give. Not built. See [`docs/PRIOR_ART.md`](docs/PRIOR_ART.md),
  [`scripts/350_motor_kv.py`](scripts/350_motor_kv.py) and
  [`scripts/360_owned_hw.py`](scripts/360_owned_hw.py).
- **The electronics were specified for parts that never arrived.** The whole ODrive
  configuration was written for an S1 on firmware 0.6.x; the drives on hand are ODrive
  **3.6** clones on modified **0.5.1**, where not one of those identifiers exists. §5 of
  [`docs/ELECTRONICS.md`](docs/ELECTRONICS.md) is now written for the real board, but none
  of it has been run. Rescaling for the real 170 Kv motors also caught
  `dc_max_positive_current` and the pack fuse being sized off *phase* current instead of
  *bus* current — the fuse was 30 A where peak bus draw is 4.9 A.
- **The second screw is gone — one screw, one carriage, one idler.** Route the belt as a
  **closed loop over two identical 29T pulleys** — the knee capstan and a second copy of it
  on the centreline — and clamp the single carriage to one strand. The kinematics close
  from either strand independently (`Y_c = const − R·φ`), the loop length is
  `2πR + 2·Y_idler` and therefore independent of carriage position, and the 23.2 : 1 ratio
  is untouched. Built and swept: [`390_onescrew_section.py`](scripts/390_onescrew_section.py)
  through [`396_fixes.py`](scripts/396_fixes.py), verified by
  [`395_verify1.py`](scripts/395_verify1.py).

  | | two-screw | one-screw |
  |---|---|---|
  | Ball screws | 2, one **left-hand** | **1, right-hand** |
  | Carriages | 2 printed, 383 g | 1 aluminium V-wheel gantry, 192 g |
  | Extrusion | 20×60, 227 mm, 352 g | **20×40, 156 mm, 164 g** |
  | Guides | 2 MGN7 rails + 4 blocks | 4 mini V-wheels |
  | Belt | strip, two anchored ends | closed loop, 742 mm |
  | Drive-end mass | 2430 g | **1588 g** |

  **842 g off the limb — 4.66 kg → 3.82 kg, 18%** — and the left-hand screw, the build's
  only special-order part, disappears along with the requirement that two screws be
  manufactured to matching lead. Peak screw column load drops 914 → 764 N because the two
  strands now oppose on one carriage.

  Verified: **107 poses, zero hard-part clashes**, knee standoff unchanged at 86 mm proud —
  the narrower rail cost nothing laterally. The five remaining flags are all cladding.

  It is not free. The **idler bracket is the new cost centre at 326 g**, because the idler
  reaction is `2·T_b` — up to **1828 N, the largest single load in the machine**. Wind the
  loop so *extension* assist loads the strand that leaves the idler lightly and it sees
  300 N in the direction that matters; that choice is free and worth making deliberately.
  The bracket was 465 g until [`400_bracket_stress.py`](scripts/400_bracket_stress.py) put
  numbers on it: the whole load path runs at **18 MPa against 240 MPa yield** and deflects
  0.0005 mm, so it was sized by what was convenient to draw rather than by any load. 7.7 mm
  plates went to 4 mm. Still not FEA — it does not cover fatigue over a million gait cycles
  or shock loading if the belt jumps.
  Added lost motion is only **+0.14°**, not the 1–3° first estimated: both strands join the
  carriage to the capstan, so they are springs in **parallel** and the short direct strand
  dominates.
- **The cladding is re-lofted and the whole assembly now sweeps clean.** 34 parts, 107
  poses, **zero hard-part clashes and zero cladding clashes** — the only remaining overlaps
  are the reference limb's own solids and the cuff gripping the limb, both intentional.
  Knee standoff unchanged at 86 mm proud.

  | | two-screw | one-screw |
  |---|---|---|
  | Thigh fairing | ±84, 168 mm, 5-post spine into the rail's middle slot | **−96…58, 154 mm**, three posterior side mounts |
  | Drive cap | −106…84, 190 mm | **−90…54, 144 mm**, now covers the idler too |

  The **spine had to move, and not to where I first said.** A 20×40's 40 mm face has slots
  at X = ±10 rather than X = 0 — but that is the smaller problem. The gantry deck sweeps
  X −32.5…32 over Y 59…197 and the idler spans X ±36.24 over Y 218.8…291.2, so between them
  they own the rail's whole **outboard** face. I concluded from that there was no mid-span
  mount left at all and fell back to two end flanges, which was wrong twice over: it
  generalised from one face of four, and a rib spanning the section is an obstruction
  rather than a mount — it cut through the extrusion, both belt strands and the gantry.
  [`398_sidemounts.py`](scripts/398_sidemounts.py) measured the alternative instead of
  arguing it: the **posterior side face is clear at three stations across all 107 poses**,
  the anterior one is blocked at every station, because everything that had to reach
  outboard to the ball nut lives on that side. Three grommeted M5 there give real mid-span
  support *and* `ELECTRONICS.md` §9's top noise mitigation — isolate the canopy instead of
  bolting it rigidly into the rail.

  The section also went **asymmetric**: the gantry reaches X −84 while nothing on the +X
  side passes 48, so a symmetric shell would need ±93 (186 mm, wider than today). Offsetting
  the superellipse centre to X −19.5 covers −93…54 and comes out **14 mm narrower** than
  what it replaces.
- **STLs, screenshots and the committed CAD are current.** 12 meshes regenerated, the
  FreeCAD screenshots rebuilt for one moving group instead of two, and
  `model/KneeExo_v6.FCStd` now matches the live file by checksum — it had gone stale again,
  the same failure an earlier audit caught. The **Blender renders are still the two-screw
  build**; `221_render_export.py` and `222_anim_export.py` carry stale part lists, flagged
  in-file and not regenerated.

- **No firmware yet.** Architecture is specified in `docs/ELECTRONICS.md`; no code written.

---

## License

[Apache License 2.0](LICENSE) — hardware, software and documentation alike. Use it, build
it, sell it, fork it; just keep the notice and the disclaimer.

Apache-2.0 rather than MIT for two reasons that matter here: it carries an **explicit
patent grant**, so nobody who contributes can later assert a patent on the mechanism
against the people using it, and its limitation-of-liability clause is far more explicit —
which is worth having on a device somebody might build and strap to a leg.

That disclaimer is not decorative. Re-read the warning at the top before you build one.

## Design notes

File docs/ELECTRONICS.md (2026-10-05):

# Electronics and control

The ODrive side. Numbers come from
[`scripts/300_drivetrain.py`](../scripts/300_drivetrain.py) and, for everything that
depends on the hardware actually in the box,
[`scripts/360_owned_hw.py`](../scripts/360_owned_hw.py). Nothing here is tested yet.

> **Revised for the hardware on hand.** This document was first written around an
> ODrive S1 and a 149 Kv motor, because that is what the analysis had asked for. The
> parts that arrived are **170 Kv C6374 motors** and **Makerbase MKS XDRIVE MINI**
> drives — ODrive **3.6** silicon on modified firmware **0.5.1**, not 0.6.x. Both
> changes are real and both are handled below; the one that matters most is that every
> API identifier had to change, because 0.5.1 and 0.6.x are not the same product.

---

## 1. Topology

```
  [36 V pack, backpack]
        |  XT90-S, 15 A fuse, latching e-stop at the waist belt
        |  12 AWG tether, service loop at the hip
        v
  [MKS XDRIVE MINI] - 3-phase -> [C6374 170 Kv]  (+ onboard AS5047P reads a
        |   ODrive 3.6, fw 0.5.1                     diametric magnet on the shaft)
        |  brake resistor 2 R / 50 W
        |
        |  CAN 500 kbit/s
        v
  [ESP32-C3 SuperMini]  -- SPI --> [AS5048A on the knee pin]  absolute joint angle
        |                -- I2C --> [BNO085 on the thigh]     gait phase
        |
        |  ESP-NOW
        v
  [ESP32-C3 SuperMini in a pocket]  assist level, mode, disable
```

Two control loops, deliberately split:

- **Fast, dumb, on the ODrive.** Current/FOC at ~20 kHz, torque command in, motor out.
  It knows nothing about walking.
- **Slow, smart, on the ESP32.** 200–500 Hz. Reads joint angle and IMU, decides *what
  torque a knee should be making right now*, sends it over CAN.

Keeping the gait logic off the motor controller means a bug in the gait code can only ever
produce a wrong torque, never a runaway commutation.

---

## 2a. Where the board physically goes, which is not optional

The topology above puts the XDRIVE MINI between the tether and the motor and says nothing about
where it is bolted. That reads like a free choice and it is not: **the AS5047P is ON the board**,
and it reads BOM D5's 6 x 2.5 mm diametric magnet glued to the motor's shaft end. From the AMS
datasheet:

| | |
|---|---|
| air gap, package face to magnet | **0.5 to 3 mm** |
| magnet centred on the package | **within 0.5 mm** |
| magnet | 6 x 2.5 diametric, which is what D5 is |

So the board sits a few millimetres off the end of the C6374's free shaft, concentric with it to
half a millimetre. It cannot live in the backpack with the battery, and it cannot be tucked
wherever there is room inside the nacelle.

**It is in the CAD now, and the flip is what made room for it.** This used to read "it is not in
the CAD: forty-two solids and not one of them is electronic -- no board, no standoffs, no cover, no
space reserved", which was a gap of the same kind as the motor having no bolts. The motor was then
turned over ([`433_drive_flip.py`](../scripts/433_drive_flip.py)) to shorten the ball screw, which
moved the link belt from above the drive to below it and left the motor's free shaft end -- the one
end the magnet can go on -- pointing up the limb into empty space.
[`434_odrive_mount.py`](../scripts/434_odrive_mount.py) puts the board there:

| surface | Y |
|---|---|
| motor's rear face, where `P27_ControllerMount` bolts on | 305.0 |
| shaft end | 307.0 |
| magnet's outer face | 309.5 |
| **board's sensor face** | **311.5** |
| board's far side, components to | 323.1 |

That is a **2.0 mm air gap**, stated as a chain of surfaces rather than a stack-up, and the script
refuses to finish if it lands outside the 0.5..3.0 above. The nacelle used to close off with a disc
across the bore at the motor's rear face -- exactly where the mount bolts -- so that closure moves
outboard and the rear of the pod is re-lofted over the board: a superelliptical swell of 5 mm,
then a 45° blunt nose ending in the drive cap's own proximal plane. Not a blister; the first
version of it was a rectangular box and read as one.

**The board's own dimensions are still guesses**, all of them flagged in the script: a 63 x 58
outline, a 55 x 50 M3 pattern, 10 mm of component height. The mount is a 20-minute reprint once
they are measured; the magnet bonded to the shaft is not.

**And no mechanical drawing is published.** Makerbase's repository
([makerbase-motor/MKS-ODrive](https://github.com/makerbase-motor/MKS-ODrive)) carries
`Hardware/MKS ODrive MINI/MKS ODRIVE MINI V1.0 Schematic.pdf` and nothing mechanical; the
community notes at [Smurf/xdrive-mini-docs](https://github.com/Smurf/xdrive-mini-docs) include a
board drawing as a PNG with no dimensions in text; the vendor listings give none. A board size of
63 x 58 mm circulates in search summaries and is not corroborated by the page it is attributed to.
**Measure the board** -- four of them are on the bench -- and in particular find where the AS5047P
sits on it, because that is the datum the mount is built around, not the board's outline.

### Startup quirks of this PCB revision

From the community notes, confirmed against the shipped firmware's behaviour: this board picks up
enough noise at startup to throw encoder errors even with an external encoder, so both startup
calibrations have to be off, and the onboard encoder needs telling what it is.

```
odrv0.axis0.config.startup_encoder_offset_calibration = False
odrv0.axis0.config.startup_closed_loop_control        = False
odrv0.axis0.encoder.config.mode                       = ENCODER_MODE_SPI_ABS_AMS
odrv0.axis0.encoder.config.abs_spi_cs_gpio_pin        = 7
odrv0.save_configuration()
```

Leave 100-200 ms between power-up and commanding closed loop.

## 2. The drive: MKS XDRIVE MINI, and what it costs

Four of these are already here at **$29.48 each**. They are ODrive **v3.6** clones —
STM32F405, DRV8301 gate drivers, NTMFS5C62NL MOSFETs, onboard AS5047P — in a 12–56 V
single-axis board.

| | XDRIVE MINI (owned ×4) | ODrive S1 (originally specced) |
|---|---|---|
| Silicon | ODrive v3.6 | ODrive S1 |
| Firmware | **modified 0.5.1** | 0.6.x |
| Bus | 12–**56** V | 12–50 V |
| Continuous | ~40 A realistic | 40 A |
| Onboard encoder | AS5047P, 14-bit SPI | MA732 |
| Price | $29.48 | $169 |
| Our peak at 170 Kv, SFU1610 | **24.8 A** | 24.8 A |

Three honest notes on that table.

**The 60 A / 120 A in the listing is not a board rating.** It is the MOSFET's
(60 V / 150 A). The real limit on v3.6 hardware is DRV8301 shunt scaling and the
thermal path off a small board, and the defensible figure is the same ~40 A class as an
S1. Treat it as a $29 S1 with older firmware, not as a 60 A drive.

**The one place it is genuinely better is the bus window.** 56 V against the S1's 50 V.
That matters here more than it looks, because regen pushes the bus *up* and §6 showed a
12S LiFePO4 pack charged to 43.8 V left only 2.2 V of headroom under a 46 V trip. Six
extra volts of device rating is six volts of somewhere for that energy to go.

**The firmware generation is the real cost**, and it is paid in §5.

### What 170 Kv changes, and what it does not

`Kt` goes 0.0641 → **0.0562 N·m/A**, so every torque costs **14% more current**: the
SFU1610 design point moves 21.7 A → **24.8 A**.

It does *not* make the motor run hotter. Copper loss for a given torque is
`P = 1.5·(T/Kt)²·R`, and for a given slot fill `Kt ∝ turns` while `R ∝ turns²` — the
turns cancel. **Copper loss for a given torque is independent of Kv.** A 170 Kv 6374 and
a 149 Kv 6374 sit at the same temperature making the same torque; the rewind moves the
burden onto the controller, not the motor. So 170 Kv is only ever a question about amps,
and at 24.8 A of a 40 A drive the answer is that it costs nothing.

What it *does* cost is the option of a much lower ratio, because that is where the amps
go — see the screw table in [`360_owned_hw.py`](../scripts/360_owned_hw.py):

| screw | ratio | T_motor | I @170 Kv | reflected J | vs limb | peak copper |
|---|---|---|---|---|---|---|
| SFU1605 | 46.4 : 1 | 0.70 N·m | 12.4 A | 0.667 | 2.22× | 5 W |
| **SFU1610 — built** | 23.2 : 1 | 1.39 N·m | **24.8 A** | 0.167 | **0.56×** | 18 W |
| **SFU1616 — target** | 14.5 : 1 | 2.23 N·m | **39.7 A** | 0.065 | **0.22×** | 47 W |
| SFU1620 | 11.6 : 1 | 2.78 N·m | 49.6 A | 0.042 | 0.14× | 74 W |

SFU1620 is out: 49.6 A is 83% of even the optimistic peak rating, with nothing left for
a stall. SFU1616 at 39.7 A is 66% of peak but **99% of continuous** — take it for the
0.22× inertia, but set `current_lim` where the drive stays cool rather than at the
mechanism's limit. 30 A still buys 21.3 N·m at the knee, and §7 starts the clinical
ceiling at 10% of that.

Speed was never the constraint and is even less so now: 170 Kv on 38.4 V free-runs at
6528 rpm and SFU1610 peaks at 1160.

### Four drives, four motors

| | |
|---|---|
| Owned | 4 × C6374 170 Kv ($150.62), 4 × XDRIVE MINI ($117.92) |
| A bilateral pair uses | 2 of each — 2 of each spare |
| Same silicon as 2 × ODrive S1 | $338 against $59 |

A bilateral build is now purely a mechanical parts question: 2 × 4.66 kg on the legs and
**one** pack, since 736 Wh against ~12 W mixed use was never close to binding.

Keeping two spares of each is the right call on a device with no FEA and no bench data
behind it.

**CAN with more than one board — this one bites.** The MINI reports itself as a
*dual-axis* ODrive. `axis1` does not physically exist but it still transmits heartbeats,
so four boards need **eight** distinct node IDs:

| board | `axis0.config.can_node_id` | `axis1.config.can_node_id` |
|---|---|---|
| 0 | 0 | 60 |
| 1 | 1 | 61 |
| 2 | 2 | 62 |
| 3 | 3 | 63 |

The fix quoted around the web is `axis1.can_node_id = 63`, which is a *single-board*
fix — do that on four boards and all four ghosts collide on 63. Better still, silence
them: `axis1.config.can_heartbeat_rate_ms = 0`. And terminate the bus at its two
physical ends only — two 120 Ω resistors for the whole bus, not one per board.

## 3. Two encoders, and why

The motor-side encoder alone is not enough. Over the 106° range of motion the screw turns
**13.66 revolutions** (6.83 at SFU1610). A single-turn magnetic encoder on the motor cannot
tell you which of those turns you are on at power-up, so you would have to home against a
hard stop every time the device is switched on. On a patient, standing, that is a
non-starter.

So:

- **Motor side** — the MINI's onboard **AS5047P**, 14-bit, 16384 CPR, SPI, chip select on
  GPIO 7. Commutation and velocity. Absolute over one turn, which is all commutation
  needs. **It is not enabled by the factory configuration** — the board ships set up for
  something else and §5 turns it on.
- **Joint side** — AS5048A, 14-bit absolute, reading a 6 mm diametric magnet.
  **THIS MOUNTING IS NOW INVALID AND NOTHING REPLACES IT YET.** The magnet used to sit in a
  counterbore in the knee pin's head, which worked because the pin was clamped to the HUB and
  so rotated with the shank while the sensor stayed still. Since
  [`457_knee_bearings.py`](../scripts/457_knee_bearings.py) the rod is clamped to the YOKE and
  is therefore **static**, and the capstan rotates around it — so a magnet in the rod's end
  would never move and would read a constant angle.

  The arrangement that replaces it, not yet drawn: magnet in a small carrier bolted to the
  **capstan's outer face** at Z 126 (it rotates, which is what is wanted), sensor on
  **`P20_KneeShroud`'s inner face**, which is static and reaches the knee axis at Z 131.5 — an
  air gap of about 2.5 mm, inside the 0.5–3.0 mm the part wants. The complication is that the
  same piece of axis is where the capstan's axial retention has to go, since a cantilevered
  stub axle locates its bearings with a washer and a screw into the rod's end. Magnet carrier,
  retention and sensor bracket are one small sub-assembly and they have to be designed
  together.

The joint encoder is the one that matters for control: it measures the *actual* knee angle
including belt stretch and any slip, which the motor-side encoder cannot see. Resolution
at 14 bits is 0.022° — far finer than needed.

A useful side effect: comparing the two gives you a free integrity check. If the joint
angle and the motor position disagree by more than a couple of degrees, the belt has
slipped or a tooth has stripped — drop torque to zero and fault.

## 3a. Two IMUs, and the question the encoders cannot be asked

The AS5048A on the knee pin measures the **angle between** two segments. It cannot measure
where either of them is *pointing*, so it reads the same number sitting in a chair as lying in
bed with the knees up — and those two want opposite things from a powered brace. Neither
encoder can tell you which way up the patient is.

Two IMUs — **thigh cuff and shank cuff** — answer that, and the important half of the answer
needs no gyro at all. At rest an accelerometer reports one thing: the direction of gravity in
its own frame. Two degrees of freedom per segment, no integration, no fusion, **no drift**. That
is the half that still works while the patient is asleep.

[`441_posture.py`](../scripts/441_posture.py) computes what each IMU reads in thirteen postures
and how far apart they are, so the thresholds below are measured rather than chosen:

| | knee angle | the IMUs differ by |
|---|---|---|
| supine flat **vs** prone flat | identical | **180°** |
| standing **vs** inverted / fallen | 8° | **180°** |
| standing **vs** supine flat | identical | **90°** |
| walking mid-swing **vs** side-lying curled | identical | **95°** |
| **sitting vs supine with knees bent up** | identical | **45°** |

The tightest of those is 45°, against the ~2° a well-mounted static accelerometer is good for.
These are not close calls. The only pair in the whole table closer than 10° is standing against
mid-stance — 8°, because mid-stance very nearly *is* standing, and both are treated the same
way. A leg-only sensor set was expected to need a third IMU on the trunk to resolve something;
it does not.

**MPU-6050, not BNO085.** The BNO085 fuses on-chip and hands the host a quaternion, which is
worth paying for when you need yaw. Nothing here needs yaw: pitch and roll are gravity-
referenced and do not drift, and the sagittal plane is the only one the knee works in. A 6-axis
part with a complementary filter on the ESP32 — a few multiply-adds at 400 Hz — is enough, and
it is a part already in the drawer. Two notes: calibrate the gyro bias at startup while the leg
is still, and buy more than you need, because the MPU-6050 is end-of-life and the supply is full
of clones.

**What they are not for.** Fused well, a pair of these is good for about a degree dynamically —
the same order as the structural compliance [`431_shank_2040.py`](../scripts/431_shank_2040.py)
measured when it sized the shank rail. So they **cannot** see that, and must never be used as an
angle reference against the AS5048A's 0.022°. They are a gross-disagreement detector: cuff slip,
a skipped tooth at 12.9°, and which way up the patient is. Cuff slip is worth singling out —
nothing else in this design can detect it at all, because every other sensor is inboard of the
straps.

**Mount them in the pockets, not with tape.** The pocket on each cuff exists to fix the sensor's
frame relative to the limb. "Roll" only means something if the sensor's axes are known, and a
sensor taped on at whatever angle the tape allowed makes every number in the table above a
guess.

## 4. What the ESP32s do

The C3 SuperMini is a good fit for this. Single RISC-V core at 160 MHz is plenty for a
500 Hz control loop, and — the thing that actually decides it — the **C3 has a TWAI
peripheral**, so it speaks CAN natively with just an SN65HVD230 transceiver. No SPI CAN
controller, no extra latency.

**Leg board:**
1. Read the AS5048A over SPI at 1 kHz.
2. Read the thigh IMU over I2C at 400 Hz.
3. Run the gait state machine and the impedance law.
4. Send `Set_Input_Torque` over CAN at 200–500 Hz.
5. Kick the ODrive watchdog. Stop kicking it and the drive coasts.
6. Log to flash or stream over BLE for tuning.

**Pocket board** (this is the good use for having a pile of them): a two-button remote over
ESP-NOW — assist level up/down, and a long-press to disable. ESP-NOW because it is
connectionless and low-latency, and does not need a network. The patient should be able to
turn assist down without stopping or getting a phone out.

Three caveats on the SuperMini specifically:

- The onboard PCB antenna on these boards is weak. Buried in a PETG fairing next to an
  aluminium rail and a running motor, BLE and ESP-NOW range will disappoint. Mount the leg
  board against the **outer** face of the thigh fairing, as far from the rail as the
  packaging allows, or use a variant with a u.FL connector.
- ~11 usable GPIOs. SPI + I2C + CAN + a status LED fits, but not much else. If you want
  loadcells or FSRs in the cuffs later, plan for a second board on the same CAN bus rather
  than trying to squeeze them onto this one.
- No 5 V rail worth using. Run a small 36 V to 5 V buck off the bus for the logic, and
  give it its own fuse — you do not want a shorted ESP32 to look like a motor fault.

## 5. ODrive configuration, starting point

**Read this before plugging anything in.** The board ships with **manufacturer-modified
ODrive 0.5.1**. `odrivetool dfu` / the `upgrade` command **bricks it** — recovery needs an
ST-Link and the dumped original image. And 0.5.6 reportedly leaves the motor dead because
the DRV8301 pin assignment moved. So: stay on 0.5.1, take the backup image before doing
anything, and never let a tutorial talk you into flashing it.

0.5.1 and 0.6.x are not the same API. Everything this document originally specified for an
S1 has a different name or does not exist:

| S1 / 0.6.x (what was written) | XDRIVE MINI / 0.5.1 (what works) |
|---|---|
| `axis0.config.motor.motor_type` | `axis0.motor.config.motor_type` |
| `axis0.config.motor.torque_constant` | `axis0.motor.config.torque_constant` |
| `axis0.config.motor.current_soft_max` | `axis0.motor.config.current_lim` |
| `axis0.config.motor.current_hard_max` | `axis0.motor.config.current_lim_margin` |
| `axis0.config.commutation_encoder` | `axis0.encoder.config.mode` |
| `EncoderId.ONBOARD_ENCODER0` | `ENCODER_MODE_SPI_ABS_AMS` + `abs_spi_cs_gpio_pin = 7` |
| `ControlMode.TORQUE_CONTROL` | `CONTROL_MODE_TORQUE_CONTROL` |
| `axis0.config.can.node_id` | `axis0.config.can_node_id` |
| `Protocol.SIMPLE` | (CAN Simple is the only protocol) |

`odrivetool`, firmware 0.5.1. Verify every identifier against 0.5.1's own docs — some of
these (`enable_brake_resistor` in particular) moved between 0.5.x point releases.

```python
# --- motor -------------------------------------------------------------
odrv0.axis0.motor.config.motor_type      = MOTOR_TYPE_HIGH_CURRENT
odrv0.axis0.motor.config.pole_pairs      = 7          # VERIFY: count the magnets, halve it
odrv0.axis0.motor.config.torque_constant = 9.549/170  # 0.0562 N.m/A -- 170 Kv, measured part
odrv0.axis0.motor.config.current_lim     = 42         # 39.7 A peak at 14.5:1 + margin
odrv0.axis0.motor.config.current_lim_margin      = 10
odrv0.axis0.motor.config.requested_current_range = 60 # sets the shunt gain; must exceed the above
odrv0.axis0.motor.config.calibration_current     = 10

# --- onboard AS5047P ---------------------------------------------------
# NOT the factory default. The board does not use its own encoder until you say so.
odrv0.axis0.encoder.config.mode             = ENCODER_MODE_SPI_ABS_AMS
odrv0.axis0.encoder.config.abs_spi_cs_gpio_pin = 7
odrv0.axis0.encoder.config.cpr              = 16384   # 14-bit
odrv0.axis0.encoder.config.pre_calibrated   = True    # after a successful offset calibration

# --- bus -------------------------------------- 12S LiFePO4, see section 6a
odrv0.config.dc_bus_overvoltage_trip_level  = 46.0    # 43.8 V charged + headroom
odrv0.config.dc_bus_undervoltage_trip_level = 31.0    # 12S at 2.6 V/cell
odrv0.config.dc_max_positive_current        =  12.0   # BUS amps, not phase -- see below
odrv0.config.dc_max_negative_current        =  -3.0   # see section 6
odrv0.config.brake_resistance               =  2.0
odrv0.config.enable_brake_resistor          = True

# --- HANDEDNESS: the one line that differs between the two legs ---------
# Both legs use the SAME right-hand ball screw -- a mirrored screw would be left-hand, which
# is a special-order part (370_no_lh_screw.py priced it and said no). The reflection is
# absorbed here instead. For a given motor direction the nut travels the same way on both
# legs, so the KNEE goes the opposite way:
#     left leg    +motor -> nut distal -> knee EXTENDS
#     right leg   +motor -> nut distal -> knee FLEXES
# Set this per leg, from the leg letter engraved on the parts (P5L / P5R):
JOINT_DIR = +1 if LEG == "L" else -1       # and apply it wherever knee angle meets motor
# Get it wrong and the knee is driven the wrong way under a 28.2 N.m assist. That is not a
# subtle failure, and it is the only difference between the two firmware images.

# --- control -----------------------------------------------------------
odrv0.axis0.controller.config.control_mode = CONTROL_MODE_TORQUE_CONTROL
odrv0.axis0.controller.config.input_mode   = INPUT_MODE_TORQUE_RAMP
odrv0.axis0.controller.config.torque_ramp_rate = 2.0  # N.m/s at the motor

# --- startup: all of it OFF --------------------------------------------
# These boards throw encoder errors from supply noise at power-up. Do not let the
# drive try to calibrate or close the loop on its own -- the ESP32 asks, once the
# rails are quiet.
odrv0.axis0.config.startup_encoder_offset_calibration = False
odrv0.axis0.config.startup_closed_loop_control        = False

# --- safety ------------------------------------------------------------
odrv0.axis0.config.enable_watchdog  = True
odrv0.axis0.config.watchdog_timeout = 0.05            # 50 ms

# --- CAN ---------------------------------------------------------------
odrv0.can.config.baud_rate         = 500000
odrv0.axis0.config.can_node_id     = 0                # 0..3, one per board
odrv0.axis1.config.can_node_id     = 60               # the GHOST axis -- see section 2
odrv0.axis1.config.can_heartbeat_rate_ms = 0          # better: silence it entirely

odrv0.save_configuration()   # 0.5.1 reboots on save; reconnect after
```

Two 0.5.1-specific traps beyond the naming:

- **`requested_current_range` must be set above `current_lim`**, and set *first*. It
  chooses the shunt amplifier gain. Leave it at a default below your limit and
  calibration fails with a current-sense saturation error that does not say so.
- **Wait 100–200 ms before requesting closed loop.** The ESP32 should sit through the
  supply transient rather than racing it. This is the documented workaround for the
  startup encoder errors these boards are known for, and it is why both `startup_*`
  flags above are `False`.

And one number that was wrong here for a long time, caught while rescaling for 170 Kv:
**`dc_max_positive_current` is bus current, not phase current.** It was set to match
`current_lim`, which conflates the two. At peak torque the motor makes 1.39 N·m at
1160 rpm — 169 W mechanical plus 18 W of copper, so **188 W off a 38.4 V bus is 4.9 A of
pack current**, against 24.8 A in the phases. The drive is bucking hard: back-EMF is only
6.8 V of a 38.4 V bus. 12 A of bus limit is already 2.4× the worst real case.

The same mistake sized the **pack fuse at 30 A** (§8). 4.9 A peak bus, and at true stall
the bus draw is *lower still* because there is no mechanical power — only the 18 W of
copper. **A 15 A fuse is the right part**, and it is the layer that has to survive a
shorted motor lead. Sizing a protective device off the wrong current is how you fit a
fuse that never blows.

CAN Simple frames the ESP32 needs (`cmd_id | node_id << 5`):

| ID | Message | Direction |
|---|---|---|
| `0x001` | Heartbeat | ODrive to ESP32 |
| `0x002` | Estop | ESP32 to ODrive |
| `0x003` | Get_Error | poll |
| `0x007` | Set_Axis_State | ESP32 to ODrive |
| `0x009` | Get_Encoder_Estimates | ODrive to ESP32 |
| `0x00E` | Set_Input_Torque | ESP32 to ODrive, the hot path |
| `0x00F` | Set_Limits | ESP32 to ODrive |

**Torque control, never position control.** A position loop makes the device fight the
patient whenever their intent differs from the trajectory, which is most of the time and is
exactly how exo research devices hurt people. The ODrive only ever receives a torque.

## 6. Regen is the thing that will bite you — and LiFePO4 makes it worse

Descending stairs, sitting down, and the eccentric phase of every step all drive the knee
backwards through the transmission and turn the motor into a generator. That current has to
go somewhere.

A pack's BMS will usually **not** accept reverse current through its discharge FETs. If it
blocks, the returning energy has nowhere to go but the DC bus capacitors, the bus voltage
climbs, and the ODrive trips on overvoltage — mid-step, with a patient on the stairs. The
failure is *safe* (the drive coasts and the joint free-swings, section 8) but it is not
acceptable as a routine event.

**With LiFePO4 this stops being a maybe.** LiFePO4 must not be charged below 0 °C, and the
chosen BMS has a low-temperature cutoff precisely to enforce that. Regen *is* charge. So on
a cold morning the BMS will refuse it — outdoors, on stairs, which is exactly the situation
the device exists for. The brake resistor is not a precaution here, it is the only path the
energy has.

A 12S LiFePO4 pack also leaves less headroom than the 10S Li-ion this was first sized for:
43.8 V at full charge against a 46 V trip is **2.2 V**, where 10S Li-ion gave 4 V. Size the
resistor for the full braking power, not a trickle.

Three things together:

1. **Fit the brake resistor.** 2 Ω / 50 W, `enable_brake_resistor = True`. This is why it
   is not optional in the BOM. Mount it where it can dump heat and cannot touch the patient
   — 50 W into a PETG fairing is a burn.
2. **Clamp `dc_max_negative_current` to a few amps.** The ODrive then limits braking torque
   rather than pushing current the pack will not take.
3. **Measure your pack before trusting it.** Put a current clamp on the pack lead and hand
   back-drive the knee. If you see negative current flowing in, the BMS accepts regen and
   you can relax the clamp. If you see nothing and the bus voltage rises, it does not.

This applies to the hoverboard pack too, and hoverboard BMSes are generally the more
restrictive of the two.

## 6a. The pack

**A123 LiFePO4, 36 V nominal, 736 Wh** (BatteryHookup M1B module) with a 7–17S smart BMS,
100 A, CAN + RS485 + UART, low-temperature cutoff.

| | |
|---|---|
| Chemistry | LiFePO4 — 3.2 V nominal, 3.65 V max, 2.5 V min per cell |
| 12S | 38.4 V nominal, **43.8 V full**, 30 V empty |
| XDRIVE MINI window | 12–56 V — fits with 12 V above a full pack |
| BMS current | 100 A against a peak bus draw near 10 A. Enormous margin |

Three things this changes from the ebike pack originally speced:

- **Undervoltage trip** moves from 30 V to 31 V (2.6 V/cell). Confirm the pack's series
  count before setting it — an 11S module empties at 27.5 V and would trip early at 31.
- **Regen headroom shrinks** and the low-temp cutoff makes refusal routine rather than
  possible. See section 6.
- **Mass.** LiFePO4 runs about 90–110 Wh/kg, so 736 Wh is roughly **7–8 kg**, against
  ~2.5 kg for the 374 Wh Li-ion pack. `300_drivetrain.py` puts mixed daily use at 12 W, so
  374 Wh already lasted 31 hours: this is roughly twice the energy for three times the
  weight. What it buys instead is real — LiFePO4 does not go into thermal runaway, the A123
  cells take enormous discharge current, and cycle life is far longer. On something strapped
  to a person that is a defensible trade, but it is a **safety and longevity** choice, not a
  range one, and 7–8 kg in a backpack needs the waist belt taking the load.

**Wiring the BMS.** The ESP32-C3 has **one** TWAI controller and it is already carrying the
ODrive at 500 kbit/s. Do not put the BMS on that bus unless you have checked both the baud
rate and the node IDs. The clean answer is to take the BMS on **UART or RS485** — the C3 has
spare UARTs — and leave CAN to the motor controller.

## 6b. Bulk bus capacitance, and why a 47 mF can is not the answer

The question comes up because a big screw-terminal electrolytic looks like free regen headroom.
Put the numbers on it against **this** bus — 12S LiFePO4, 43.8 V charged, tripping at 46.0 V:

| | |
|---|---|
| energy a 47 000 µF cap holds at 43.8 V | **45 J** |
| energy it can *absorb* in the 2.2 V window before the trip | **4.6 J** |
| a controlled sit-down, 80 kg through ~0.45 m | ~350 J at the body, tens of joules at the knee |

So roughly **one part in ten of a single sit**, and nothing at all for stairs. Bulk capacitance
is not a regen strategy here; the 2 Ω / 50 W brake resistor in section 6 is, and it stays.

Three further reasons not to put that particular part on the patient's bus:

1. **Voltage class.** A 50 V capacitor sits at 88 % of its rating on a 43.8 V bus continuously,
   and 92 % at the overvoltage trip. Electrolytics want derating, not margin-free operation, and
   this one would spend its life at the top of its range. Anything added here should be **63 V
   or better**.
2. **Inrush.** Connecting 47 mF to a charged pack dumps ~45 J into the connector in
   milliseconds, at a peak current limited only by ESR and wiring. It will pit or weld a
   connector and can trip the BMS. Bulk capacitance above a few hundred µF needs a **precharge
   resistor and a soft-start**, which is a circuit, not a part.
3. **Stored energy on a worn device.** 45 J remains on that bus after the power is off. A
   **bleed resistor** is then mandatory, and it is one more thing to get wrong on something
   strapped to a patient.

**Where it genuinely helps: the bench.** A laboratory supply cannot absorb regen at all, so the
first hand-spin test in section 10 — "confirm the resistor gets warm rather than the bus voltage
spiking" — is exactly where a large capacitor earns its keep, and at a 24 V bench voltage a 50 V
part has real margin and gives ~7.6 J of buffer. Use it there, with a precharge resistor, and
leave it out of the pack.

## 7. Control strategy

Start with the simplest thing that helps with stairs, which is what this is for.

**Phase-scheduled impedance.** At each tick:

```
tau_cmd = K(phase) * (theta_ref(phase) - theta) - B(phase) * theta_dot + tau_ff(phase)
```

with `theta` from the joint encoder and the phase from the IMU + angle. Four phases are
enough to be useful:

| Phase | What the exo should do | Rough setting |
|---|---|---|
| Stance, knee flexing (loading) | Resist collapse | Moderate K, extension bias |
| Stance, knee extending (push-up onto the step) | **Assist extension — this is the one that matters for stairs** | Highest `tau_ff`, ramped with flexion angle |
| Swing, flexion | Small flexion torque to help foot clearance | Low K, small `tau_ff` |
| Swing, extension | Near zero, let the leg swing | K and B near zero |

Two hard clamps on top, in the ESP32, before anything reaches CAN:

- **Never command extension torque near full extension.** Hyperextension is an injury, and
  the mechanism has the authority to cause one. Taper `tau_cmd` to zero over the last 10°.
- **Absolute torque ceiling** well below the 28.2 N·m the mechanism can make. Start at
  **10%** and have the physio raise it.

Sit-to-stand is the same extension-assist law with a slower ramp, and is the right thing to
tune first because it is done seated, in one place, with something to hold.

## 8. Safety

The good news first: **the failure mode is benign by construction.** A 10 mm-lead ball
screw backdrives at ~89% efficiency, so loss of power, a blown fuse, a tripped drive or a
crashed ESP32 all leave a free-swinging passive brace, not a locked leg. Nothing in the
design can jam the knee. That is worth protecting — do not "improve" it later by adding a
self-locking screw or a fail-engaged brake.

Layered limits, each independent of the others:

| Layer | Limit | Fails to |
|---|---|---|
| Gait code | 10% assist ceiling, hyperextension taper | wrong torque, bounded |
| ODrive | `current_lim` 42 A, torque ramp rate | current trip, coast |
| Watchdog | 50 ms without CAN traffic | idle, coast |
| Mechanical | hard stops at −2° and +104° | hard stop |
| E-stop | latching NC at the waist belt, cuts power | dead, coast |
| Fuse | **15 A** at the pack — 4.9 A peak bus current, see §5 | dead, coast |

Testing progression, and do not skip steps:

1. Bench, no limb, screws driven by hand — check the two encoders agree across the range.
2. Bench, powered, torque commands only, joint loaded with a weight.
3. Worn, seated, sit-to-stand only, 10% assist, hand on a rail.
4. Level walking, parallel bars or a handrail, spotter.
5. Stairs, handrail, spotter.

This is not a certified device and should not be treated as one. Get the physio involved
before step 3, and keep the assist ceiling under their control rather than the patient's.

## 8a. The posture gate

Assist is **armed only when the leg's attitude is consistent with being upright**: standing,
either phase of walking, sitting, sit-to-stand, stair ascent. In every other posture in the
table above — in bed, prone, side-lying, inverted — the controller commands zero torque and
will not leave that state however the gait machine is feeling.

The closest any armed posture comes to any disarmed one is **45°**, so this is not a delicate
threshold.

Three properties make it worth more than the classification it rests on:

- it is **accelerometer-only**, so it cannot drift, and it is still correct after eight hours
  of sleep with the device powered;
- it is evaluated **outside the gait state machine**, so a bug in the gait code cannot arm it.
  That is the same argument section 1 already makes one level down about keeping gait logic off
  the motor controller;
- it fails **closed**. Lose an IMU, lose I²C, read something not in the table — disarm.

28.2 N·m into a post-operative knee, in bed, at three in the morning, because a state machine
mis-fired, is the failure this design should be most afraid of. The guard against it costs two
parts that are already in the drawer.

## 9. Noise

Not analysed, and it should be, because this is worn in public and a device that whines
marks the wearer out. Nothing here is measured — it is reasoning from component type.

Likely sources, in the order I would expect them to matter:

1. **Ball nut recirculation.** Balls entering and leaving the return tube: roughly
   15 balls × 19 rev/s ≈ **290 Hz** and harmonics at peak speed, right where hearing is
   most sensitive. Choosing SFU1610 over 1605 already halved screw speed to 1160 rpm,
   and recirculation noise rises steeply with rpm. Note the 1:1.6 overdrive does **not**
   help here: it slows the *motor* to 725 rpm and leaves the screw at 1160. An SFU1616
   would halve this, which is the one thing it would still do better than the overdrive.
2. **The fairings as a soundboard.** Possibly worse than the source. `P21` was a 284 mm
   canopy of ~3 mm PETG on a **rigid spine** straight into the rail's middle slot — a
   direct structure-borne path into a large thin panel. **That spine no longer exists**:
   the one-screw rebuild put the gantry and the idler on the rail's outboard face, leaving
   nowhere for it, and the canopy now hangs on three grommeted mounts into the posterior
   side face. The layout forced the mitigation listed below before it was ever chosen.
3. **Motor** — FOC and 24 kHz PWM are both inaudible, but torque ripple at 6× electrical
   lands near **800 Hz** at peak speed.
4. **The 1:1 linking belt**, ~390 Hz tooth passage.
5. **Mini V-wheels** — Delrin on aluminium, rolling. Quieter than the MGN7H blocks they
   replaced, but watch for flats: [`401_vwheel_load.py`](../scripts/401_vwheel_load.py)
   puts the flank contact at 91 MPa against a ~101 MPa yield onset even at the widened
   70 mm spacing.
6. **The 1:1.6 link belt**, 20T at 725 rpm ≈ 242 Hz tooth passage — new, and low.

The capstan barely contributes: the HTD-8M belt is anchored at both ends and only lays
onto and peels off the same 180° wrap, so tooth passage is ~24 Hz. A geared or belted
reduction at the knee would be far worse.

Mitigations, cheapest first — **isolate the fairings** (rubber grommets instead of the
rigid spine; highest leverage and it costs grams — and as of the one-screw rebuild this is
no longer optional, it is simply how the canopy mounts), **constrained-layer damping** on the
inside of the canopy, and **correct screw preload and grease**. The instinct to stiffen
the fairing mounts against rattle is backwards here.

Treat all of that as provisional until step 2 below.

## 10. Bring-up order

0. **Back up the firmware before anything else.** `odrivetool` will offer to upgrade the
   board and that bricks it. Pull the image with an ST-Link, or at minimum keep the
   community dump to hand, *then* connect. Also: open a motor, count the magnets in the
   bell, halve it, and set `pole_pairs` to that. C63xx ships as both 14-pole and 12-pole
   and a wrong count makes calibration fail or commutation run rough — two minutes now
   against an afternoon of chasing a phantom fault.
1. ODrive on the bench, motor unloaded, `AXIS_STATE_MOTOR_CALIBRATION` and encoder offset
   calibration. Set `requested_current_range` *before* `current_lim`. Confirm smooth torque
   control by hand.
2. Add the brake resistor. Spin the motor by hand fast and confirm the resistor gets warm
   rather than the bus voltage spiking. **While the drivetrain is on the bench, run it
   unloaded through the speed range and measure the noise** — even a phone SPL app will
   do. The fairing mounting design depends on the answer and is cheap to change now and
   expensive later.
3. Regen test on the actual pack (section 6, item 3). Set `dc_max_negative_current` from
   what you measure.
4. ESP32 on CAN — heartbeat in, `Set_Input_Torque` out, watchdog kicking. Verify the drive
   coasts when you unplug the ESP32. **Verify this before it ever goes near a leg.** With
   more than one board on the bus, confirm the ghost `axis1` heartbeats are silenced or
   uniquely numbered first (§2), otherwise you will chase a bus fault that is really two
   boards claiming one ID.
5. AS5048A in the knee pin. Sweep the joint by hand and check joint angle against motor
   position over the full range — they should track to within a degree.
6. IMU and gait phase, logging only, no torque. Walk with it dead and check the phase
   classifier on the logs.
7. Only then enable torque, at 10%.

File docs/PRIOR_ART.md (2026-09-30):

# What everyone else is actually doing

Surveyed September 2026. The short version: **the field has converged on quasi-direct
drive at the joint**, and this design already sits inside that band without having set out
to. The interesting finding is not that remote actuation is wrong — it is that the two
problems this project has been circling (torque sensing, and reflected inertia) have a
different answer than the one it was heading towards.

---

## 1. Quasi-direct drive is the current paradigm

High torque-density motor, **low** gear ratio, mounted at the joint. Backdrivability comes
from the ratio being small, not from a spring, a cable or a clutch.

| | Ratio |
|---|---|
| Soft exosuit, Bowden-driven | ~50 : 1 |
| QDD hip exo, custom planetary | 36 : 1 |
| **This design — SFU1610 screw + capstan, as built** | **23.2 : 1** |
| **This design — SFU1616, the target** | **14.5 : 1** |
| QDD knee | 9 : 1 |
| QDD ankle | 8 : 1 |

Published QDD performance to benchmark against:

| | Mass | Nominal torque | Backdrive | Bandwidth |
|---|---|---|---|---|
| QDD hip exo | 3.4 kg | 17.5 N·m | 0.40 N·m | 62.4 Hz |
| QDD cable knee exo | — | — | 2.58 N·m peak resistance | — |
| conventional knee exo they benchmark against | — | — | 8.0 N·m | — |
| **this design** | 4.66 kg | 28.2 N·m | see below | not modelled |

Torque density is comparable — 6.1 N·m/kg here against 5.1 for the QDD hip. The gap is
elsewhere.

## 2. The finding that matters: QDD needs no torque sensor

> "Assistive torque control in QDD systems is achieved through **proprioceptive sensing
> instead of torque sensors**."

At a low enough ratio, transmission friction is small next to the torque being commanded,
so **motor current is a good enough measurement of joint torque**. No load cell, no series
spring, no strain gauge.

That answers a question this project spent a while on. The load cell was only ever needed
because a Bowden sheath sits between the motor and the joint and eats 20–30% of the
tension in a posture-dependent way. Keep the actuator on the limb and the problem does not
exist — which is a strong argument for *not* going remote.

## 3. Bowden friction is managed, not solved

The literature is candid: nonlinear friction between inner cable and sheath is "a major
source of hysteresis and phase delay", and cable systems "suffer from mechanical losses
due to friction, cable stretch, and hysteresis ... and require periodic maintenance".

The responses are all mitigations:

- **Learning-based repetitive control** — iterative learning that adapts the reference
  trajectory to cancel hysteresis without modelling it. Works because gait is periodic.
- **Loop routing** — reduces the effect of bending, at the cost of *higher* total friction.
- **Redirection pulleys** instead of sheath bends — lower friction, more mechanical
  complexity.

Nobody has made it go away. `scripts/340_tendon.py` in this repo computes 78% → 69%
efficiency as the hip flexes, which is consistent with all of the above.

## 4. What shipped commercially: motors at the knee

**Arc'teryx × Skip MO/GO** — a Google X spinout, four years of development, $5,000, sold as
"the world's first powered clothing". Motors **at the knees**, carbon-fibre structure
distributing load along the leg, ~40% boost walking uphill, three hours of hard uphill at
maximum assist, and it **regenerates on the descent**.

Two things to take from that:

- The commercial answer for a knee is joint-mounted, not remote — and they note the knee is
  the harder joint to do, which is why most products target the hip.
- Regenerating downhill is treated as a feature, not a hazard. This repo's
  `docs/ELECTRONICS.md` §6 reaches the same conclusion from the other direction: with
  LiFePO4 and a low-temperature cutoff the pack will sometimes refuse that energy, so the
  brake resistor is mandatory.

## 5. Where this design is actually weak

Not torque density, and not the architecture. It is **reflected inertia**, and it comes
straight from the 23.2 : 1 being at the top of the QDD band rather than the bottom:

| Knee swing acceleration | Torque from reflected inertia | Limb alone |
|---|---|---|
| 30 rad/s² | 5.0 N·m | 9.0 N·m |
| 60 rad/s² | 10.0 N·m | 18.0 N·m |
| 129 rad/s² (60° in 0.2 s) | **21.5 N·m** | 38.7 N·m |

Static backdrive is fine — about 1.8 N·m, and most of that is motor cogging multiplied by
the ratio. It is the dynamic term that hurts, and it is 0.56× the limb's own inertia at
every acceleration.

The published backdrive figures above are low-speed resistance measurements and are not
directly comparable, but the direction is clear.

## 6. So what would actually improve this device

In order of leverage:

1. **Lower the ratio — but not as far as the field does, and not with a bigger motor.**
   See [`scripts/350_motor_kv.py`](../scripts/350_motor_kv.py). Reflected inertia is
   `J_rotor × N²`, and the tempting move is to cut N. But the motor then has to make
   `32.3/N` N·m, and torque goes as `R²L` while inertia goes as `mR²` — so **buying torque
   with diameter buys inertia straight back**:

   | motor | J_rotor | lowest workable ratio | reflected J | vs. limb |
   |---|---|---|---|---|
   | **6374 — owned ×4** | 3.10e-4 | 14 : 1 | **0.065 kg·m²** | **0.22×** |
   | 6384 | 3.88e-4 | 11.6 : 1 | 0.052 kg·m² | 0.17× |
   | 8085 | 1.13e-3 | 14 : 1 | 0.221 kg·m² | 0.74× |
   | 8308 pancake | 9.5e-4 | 12 : 1 | 0.128 kg·m² | 0.43× |
   | 110 mm pancake | 3.55e-3 | 6 : 1 | 0.128 kg·m² | 0.43× |

   The best point is a **longer 6374, not a fatter one** — but not even that, once the
   controller is in the picture. A 6384 at 11.6 : 1 (SFU1620) does reach 0.17×, against
   0.22× for the owned 6374 at 14.5 : 1 (SFU1616). That advantage is real and it is
   **0.013 kg·m², 4% of the limb's own inertia** — and it costs 49.6 A against 39.7 A at
   the 170 Kv motors on hand, which is above any believable continuous rating for the
   drives on hand. See [`scripts/360_owned_hw.py`](../scripts/360_owned_hw.py).

   So: **don't buy the motor, buy the screw.** SFU1616, 16 mm lead, and the nut is still
   OD 36 — the same carriage bore the model already carries at `NUT_R = 18`. Verify that
   on the supplier drawing before ordering, because it is the single fact that decides
   whether this is a screw swap or a carriage rebuild.
2. **Keep the actuator on the limb.** It is what the commercial product does, it removes
   the need for any torque sensor, and it avoids a failure mode the literature has spent
   fifteen years managing rather than fixing.
3. **Measure backdrive on the bench** before trusting any of the above. Nothing in this
   repository has been measured on hardware.

---

## Sources

- [Quasi-Direct Drive Actuation for a Lightweight Hip Exoskeleton with High Backdrivability and High Bandwidth](https://arxiv.org/pdf/2004.00467) — Su et al., arXiv
- [A Quasi-Direct-Drive Cable Actuation System for an Intrinsically Safe Knee Exoskeleton](https://haosu-robotics.github.io/images/Paper/AQuasiDirectDriveCableActuationSystemforAnIntrinsicallySafeKneeExoskeleton.pdf)
- [Design and Validation of a Modular, Backdrivable Ankle Exoskeleton (M-BLUE)](https://pmc.ncbi.nlm.nih.gov/articles/PMC11548846/) — Zhao, Walters, Gregg
- [Design and Control of a Quasi-Direct Drive Soft Hybrid Knee Exoskeleton](https://arxiv.org/pdf/1902.07106)
- [Learning-Based Repetitive Control of a Bowden-Cable-Actuated Exoskeleton with Frictional Hysteresis](https://www.ncbi.nlm.nih.gov/pmc/articles/PMC9611146/)
- [Mechanical design and friction modelling of a cable-driven upper-limb exoskeleton](https://www.sciencedirect.com/science/article/pii/S0094114X22000234)
- [Series-elastic actuator with two degree-of-freedom PID control improves torque control in a powered knee exoskeleton](https://www.cambridge.org/core/journals/wearable-technologies/article/serieselastic-actuator-with-two-degreeoffreedom-pid-control-improves-torque-control-in-a-powere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)
- [Arc'teryx × Skip MO/GO powered pants](https://gearjunkie.com/apparel/arcteryx-skip-mogo-exoskeleton-pants) — GearJunkie
- [Skip and Arc'teryx exoskeleton pants](https://newatlas.com/technology/skip-arcteryx-powered-pants/) — New Atlas

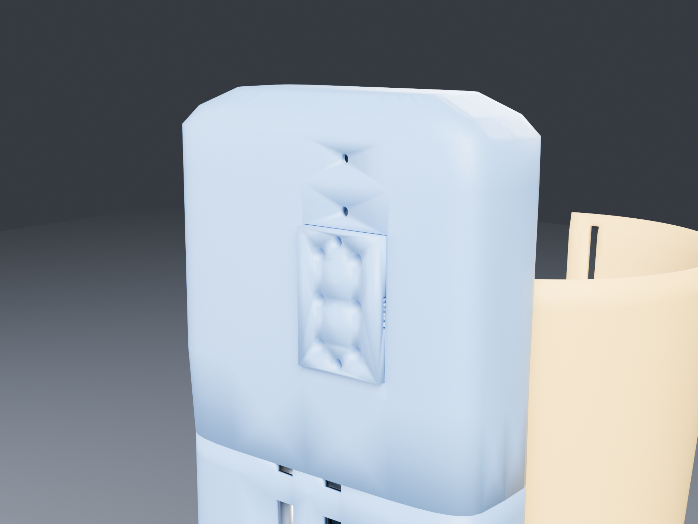
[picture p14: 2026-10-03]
renders/flexed_40deg/05_drive_clad.png

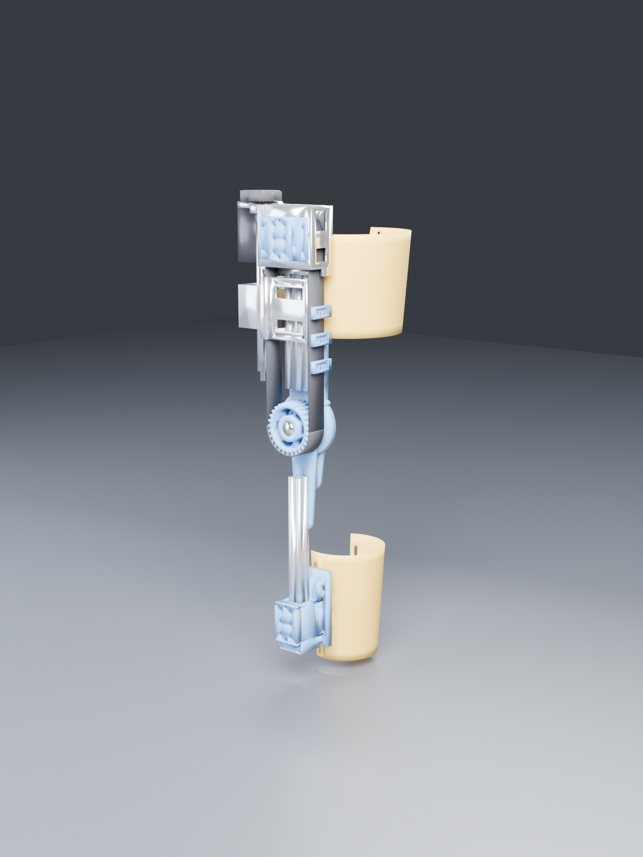
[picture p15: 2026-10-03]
renders/extended_0deg/02_hero_open.png

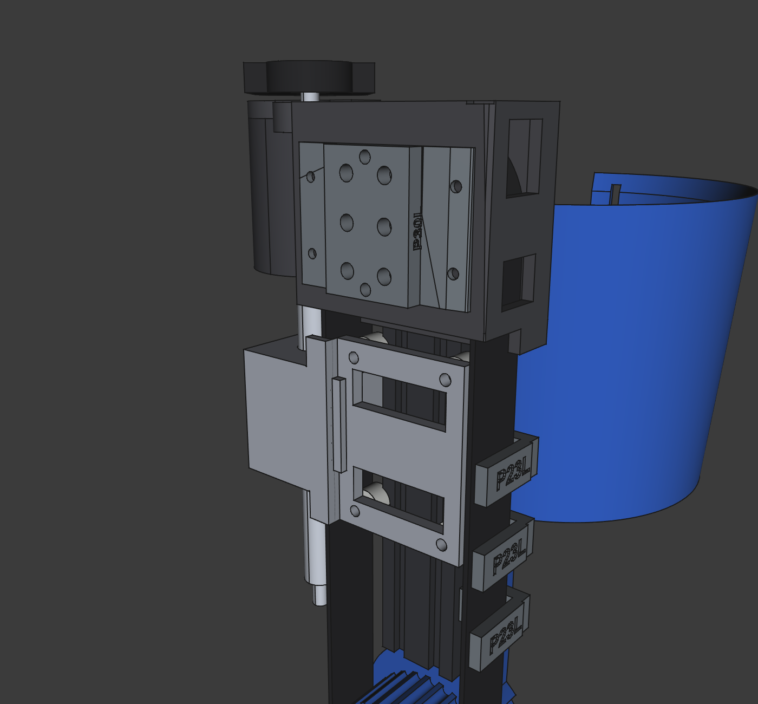
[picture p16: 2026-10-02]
renders/cad/drive_antlat_open.png

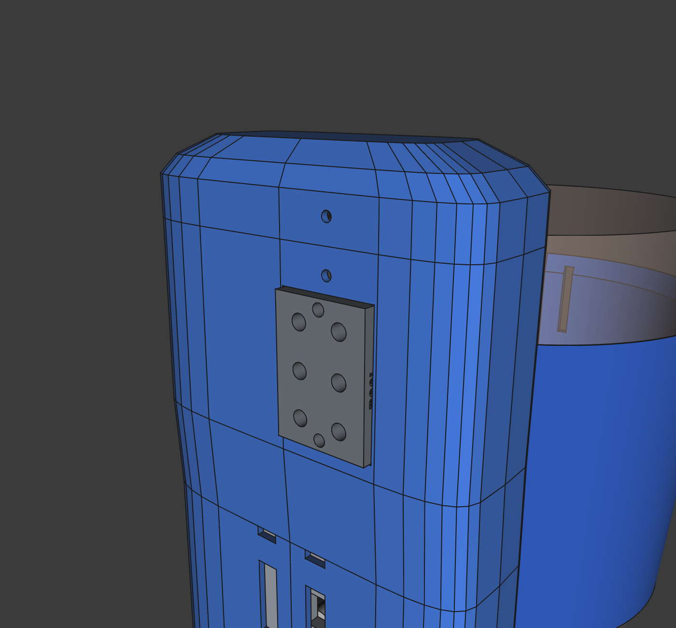
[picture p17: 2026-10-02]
renders/cad/drive_antlat_clad.png

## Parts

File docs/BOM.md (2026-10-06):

# Build list

Quantities are for **one** knee unit (single leg). Prices are indicative USD from the
usual suspects (AliExpress / Amazon / ODrive) — order-of-magnitude, not quotes.

Every mechanism-derived number below comes out of
[`scripts/300_drivetrain.py`](../scripts/300_drivetrain.py). Run it before ordering,
because changing one assumption moves several lines at once.

**Ordering for both legs?** Only the symmetric lines double in quantity — extrusion, belts,
pulleys, motors, drive, V-wheels, bearings, fasteners, neoprene sleeves, webbing. The printed
printed parts double in *count* but are **new part numbers, not more of the same**: 17 L + 17 R
(1655 g of filament per leg, 103 h of printing), and **no machined parts at all** since
[`802_no_metal.py`](../scripts/802_no_metal.py). Sixteen of the seventeen are engraved with their
leg letter; the 29T capstan is the exception, because 414 searched 16 stations × 36 bearings and
found nowhere on it that is hidden at an open joint. The **ball screw stays right-hand on both legs** — a mirrored screw would be left-hand,
which is a special-order premium part, and the reflection is absorbed by one sign in firmware
instead. See [`700_handedness.py`](../scripts/700_handedness.py) and the README's
"Building the pair".

---

## 1. Open decision you must settle before ordering

The screw lead sets the total knee-to-motor ratio, and reflected rotor inertia goes as
the **square** of that ratio. This is the most important choice in the build:

| Screw | Ratio | Reflected J | vs. limb's own J | Peak current @170 Kv | Nut OD |
|---|---|---|---|---|---|
| SFU1605 | 46.4 | 0.667 kg·m² | **2.22x** | 12.4 A | 28 mm |
| SFU1610, 1:1 link | 23.2 | 0.167 kg·m² | 0.56x | 24.8 A | 36 mm |
| **SFU1610 + 1:1.6 overdrive — built** | **14.5** | **0.065 kg·m²** | **0.22x** | **39.7 A** | 36 mm |
| **SFU1616 — target** | 14.5 | 0.065 kg·m² | **0.22x** | 39.7 A | 36 mm |
| SFU1620 | 11.6 | 0.042 kg·m² | 0.14x | 49.6 A | 40 mm |

Currents are at the **170 Kv** motors actually on hand — 14% higher than the 149 Kv this
was first sized for. That costs controller amps and, because copper loss for a given
torque is independent of Kv, no motor heat at all. See
[`360_owned_hw.py`](../scripts/360_owned_hw.py).

Reflected inertia is what the patient feels **when the motor is off** — a dead battery, a
fault trip, or the free-swing phase of every step. At SFU1605 the leg would feel roughly
three times as heavy to swing as it does bare. For someone already struggling to walk,
that is a worse device than no device.

You cannot fix this by moving the reduction around: only the *total* ratio matters, so
"SFU1620 plus a 4:1 belt" is inertially identical to SFU1605 direct.

**Recommendation: SFU1610, and it fits as drawn.**

This repository previously said the 1610 nut fouled the belt by 1.1 mm and the screws
would have to move out to X = ±62, widening the pack by 8 mm. **That was wrong.** It came
from projecting the nut and the belt onto the X axis and comparing edges — 58 − 18 = 40
against the belt's outer face, then at 41.1 and now 38.46 (423) — while ignoring Y. The nut sits at `carrA + 36` and
its belt run ends at `carrA − 24`, so they are a constant **60 mm apart along the limb at
every pose, by construction**. Swept over all 107 poses, the nut/belt overlap is
**0.000 cm³ for OD 28, OD 36 and OD 40 alike**.

What does share length with the belt is the screw *shaft*, and at r = 7.9 it is clear
until |X| < 49. So there is roughly 8 mm per side of inboard slack available if you want
the pack narrower — for 1610 the binding limit becomes the nut against the extrusion
(|X| ≥ 30 + 18 = 48), so about X = ±50. Not modelled; the current ±58 is what is drawn.

**This is now built.** [`240_nut1610.py`](../scripts/240_nut1610.py) draws the nuts at
OD 36 and grows the carriage body to X 34…80, Z 84…128 so the bore is captured with a
3.8 mm wall; [`241_fixups.py`](../scripts/241_fixups.py) clears the two clashes that
caused. Screws stay at **X = ±58**. Swept clean over all 107 poses. The stale `SFU1620`
labels are corrected too.

**Order SFU1610, RH and LH.** Both from the same supplier in the same batch — mismatched
lead accuracy or nut preload between the two shows up directly as the differential
drifting, and there is no adjustment for it. Each screw only needs **162 mm of thread**
(the nut bodies live at Y 121…283); the rest is bearing seats.

---

## 2. Drive

| # | Part | Qty | Notes | ~USD |
|---|---|---|---|---|
| D1 | Ball screw **SFU1605, 5 mm lead, 200 mm**, BK/BF12 machined ends | 1 | **BOUGHT — this line used to read SFU1610 / 180 mm and the lead is the whole ratio.** 5 mm doubles the screw reduction to 46.4:1 before the link belt, which is why D7's motor pulley went from 32T to 38T. 1610 at 200 mm is not stocked anywhere outside China ([`443_screw_sourcing.py`](../scripts/443_screw_sourcing.py)); 1605 is everywhere. The ends are machined ⌀10 × 11 floating / ⌀12 × 25 + M12 × 1 × 14 + ⌀10 × 15 fixed, leaving **135 mm of thread against the 110 mm the nut's travel needs** ([`446_sfu1605_set.py`](../scripts/446_sfu1605_set.py)). Historically, when it was the 1610: 68.3 mm stroke; the nut sweeps Y 73…183 so 110 mm of thread is used, the rest is bearing seats. Axis at **X = −62**, moved 4 mm outboard of the old −58 so the nut clears the return strand. **180, not the 260 this line used to say, and not the 330 before that.** The screw spanned Y 57…314 only because the link belt sat on TOP of the drive: 131 mm of shaft above the nut's travel, carrying torque and nothing else. Turning the motor over ([`433_drive_flip.py`](../scripts/433_drive_flip.py)) moves the belt under the motor to Y 208…223 and the screw stops at Y 235 — a ⌀8 journal at Y 57…71 for the KP08, thread Y 71…204, and a ⌀8 journal at Y 204…235 for the 20T pulley and the 608. 178 mm of screw, so order 180: **79 mm and about 123 g of steel less than the last revision.** **The ⌀8 journals are the model's fiction**: the vendor drawing for a real machined-end screw is ⌀10 × 15 / M12 × 1 × 14 / ⌀12 × 25, so both journals are ⌀10 and every bearing seated on them steps up with them — see D8 and D8a. [`426_screw_ends.py`](../scripts/426_screw_ends.py), [`445_screw_foot.py`](../scripts/445_screw_foot.py). **Built in v8** as Y 60…71 floating (⌀10 × 11), thread Y 71…206, ⌀12 × 25 fixed journal Y 206…231 — 171 mm of the 200 bought, 29 parted off ([`459_v8_drivetrain.py`](../scripts/459_v8_drivetrain.py)) | 32 |
| ~~D2~~ | ~~Ball screw SFU1610, **LH**~~ | **0** | **Deleted.** The closed-loop belt over two 29T pulleys makes one carriage do both jobs, so there is no left-hand thread and no special order anywhere in the build. [`390_onescrew_section.py`](../scripts/390_onescrew_section.py) | −70 |
| D3 | SFU1605 **flanged** ball nut + **DSG16H housing** — **IN THE BOX** | 1 | **This line said FLANGELESS and that was wrong**: SFU/RM nuts always carry a flange, and the set ships the aluminium DSG16H housing too — which is the bought version of everything `P3_GantryPlate_Printed` was drawn to do. The nut bolts through its flange into the housing and the housing presents flat tapped faces, in aluminium, which does not creep under 764 N the way a printed pocket does. **`P3_GantryPlate_Printed` has to be redrawn around it** and the nut's envelope grows past the 36 × 36 × 42 box the model carries. Everything below describes the flangeless nut this line used to specify and is kept only because the gantry still contains it: Trapped axially between two end plates in the gantry rather than clamped radially — a 36.4 mm bore through a 40 mm housing severs it, and the load is along Y anyway. **Axial trapping is not enough on its own**: a flangeless nut in a round pocket has nothing stopping it turning with the screw, so two radial **M5 set screws** at Y 149 and 173 bear on the nut body through the gantry's outboard wall. File a flat on the nut for them. [`424_belt_tunnel.py`](../scripts/424_belt_tunnel.py) | inc. |
| D4 | BLDC outrunner C6374, **170 Kv**, 8 mm shaft | 1 | **Owned — 4 of them, $32–40 each.** 24.8 A peak at SFU1610. ~800 g, the heaviest single item | 38 |
| D5 | Diametric magnet 6 x 2.5 mm | 1 | Glued to the motor shaft end for the drive's onboard AS5047P | 3 |
| D6 | HTD-5M belt, **270 mm / 54T**, **15 mm** wide, closed loop | 1 | **54T is exact** at the 60.8 mm centre distance with the 38T:20T of D7 — the 32T it replaced wanted 50.6T, which is no belt at all ([`446_sfu1605_set.py`](../scripts/446_sfu1605_set.py)). Motor to screw, **under** the motor at Y 208…223 since the flip — the shortened screw is what that bought. Centre distance 61 mm. 15 mm, not 9: it now carries the overdrive, ~153 N tight side. **The CAD had this belt as 12 mm wide and 13 mm longer than a 61 mm centre distance allows** — a constant-width capsule rather than the hull of the two pulleys — so the motor's plate sat 3 mm inside it, and a cover sized to that envelope would have been 13 mm bigger than the belt. Rebuilt in [`433_drive_flip.py`](../scripts/433_drive_flip.py); everything proximal of the belt moved up 3 mm | 10 |
| D7 | HTD-5M **38T** (motor) + **20T** (screw) pulleys — **PRINT BOTH** | 1 each | **The 38T came off the buy list when the hub stopped being plastic.** A **rigid flange coupling** (D7a) sunk into the back of the printed pulley and a 3 mm aluminium plate on the front, bolted through: the grub screws then grip the shaft **steel on steel**, and the torque reaches the plastic through 4 bolts on an ⌀18 circle instead of one dimple at the ⌀8 bore — **37 N per bolt, 1.08 MPa, a factor of 37**, where a grub screw into PETG was a factor of about 1. The flange is buried in a body 27.5 mm in radius with 16.8 mm of wall outboard of the bolts, and the aluminium plate doubles as the belt flange a 15 mm belt on a 60 mm pulley wants anyway ([`449_flange_hub.py`](../scripts/449_flange_hub.py)). **P25_MotorNacelle needs a ⌀16 clearance bore on the motor axis** at Y 201…204 for the coupling's boss, cut in `434_odrive_mount.py` itself and not patched after it. The previous reasoning, which was right until the coupling appeared: **the split is about hubs and heat, not teeth.** Both tooth loads are trivial — 2.0 N and 5.2 N per tooth against the printed capstan's 52.7 — but the motor pulley takes **331 N of tangential load through a grub screw into a ⌀8 shaft**, and it is the only pulley in the machine clamped to something that runs past PETG's 80 °C glass transition. A printed hub there does not break, it **creeps**, the belt skips, and the motor's encoder stops corresponding to the knee angle. Buy that one in aluminium for $8. The 20T sees 113 N on ⌀12 at room temperature and is the awkward one to buy anyway — a 20T HTD-5M in a ⌀12 bore is not a stock item ([`447_printed_pulleys.py`](../scripts/447_printed_pulleys.py)). **A 1:1.9 OVERDRIVE, and both numbers changed when the 5 mm-lead screw was bought.** 32T:20T at a 5 mm lead is 29.0:1 and **0.87× the limb's own inertia** — the leg would feel 87% heavier with the power off. 38T:20T is 24.4:1, 0.62×, 23.5 A, and it is the only pulley under the ⌀63 can that also lands on a whole belt size (54T). The screw pulley's bore is **⌀12, not ⌀8**: it sits on the bearing journal of the machined fixed end ([`446_sfu1605_set.py`](../scripts/446_sfu1605_set.py)). Was: **a 1:1.6 overdrive, not 1:1.** This is what puts the total ratio at 14.5:1 with the SFU1610 — see [`404_link_ratio.py`](../scripts/404_link_ratio.py). Gearing here is nearly free because this belt sits on the motor side of the screw's advantage and carries 85 N, not the 764 N the capstan loop carries | 14 |
| D7a | **Rigid flange shaft coupling, ⌀8 bore** | 1 (sold in 4s) | Steel, ~⌀25 flange × 4 thick, ⌀13 boss × 11, 4 bolt holes on ⌀18, 2 grub screws. It is what makes D7's motor pulley printable. **Use steel spacers in the bolt holes, cut 0.1 mm proud of the printed hub**, so the flange and the backing plate clamp steel-to-steel: PETG creeps under sustained bolt preload — an M3 at 1.2 N·m is ~42 MPa under the washer, five times what it holds without flowing — and creep runs fast at the temperature this particular shaft reaches. **Every dimension here is read off a product photo. Measure yours** | 10 |
| D7b | 3 mm aluminium plate, ~55 mm square | 1 | The backing plate of the same sandwich, and the belt flange on that face | 3 |
| D8 | **BF12 floating-end screw support** — **IN THE BOX** | 1 | The SFU1605 set bought in October 2026 ships BK12, BF12, the M12 locknut, a circlip, the nut, a DSG16H nut housing and a flexible coupler, so this line and D8a and D9 are all sourced. It still has nothing to bolt to: **P32_ScrewFoot**. Previously, and the reasoning stands: The screw's **lower** end only, and **this line was wrong twice over**. It read "KP08 / KFL08", naming two parts that are not interchangeable: KP is a foot-mounted pillow block that bolts to a face **parallel** to the shaft, KFL a two-bolt diamond flange that bolts to a face **perpendicular** to it. Choosing between them is choosing which face you have — and [`445_screw_foot.py`](../scripts/445_screw_foot.py) went to look and found **neither**: within r 40 of the lower journal there is the knee yoke's corner 32 mm away in X and 18 mm below in Z, the belt's drive run, and cladding. No boss, no bolt pattern, no block. The same defect D8a records at the other end of the same screw. Beyond that, KP/KFL are shaft blocks for plain round rail — a pressed self-aligning insert — whereas this screw is sold **"FK/FF end machined"** and the vendor drawing shows ⌀10 × 15, then M12 × 1 × 14 for a locknut, then ⌀12 × 25 for the pulley. Those ends are cut for the FK/FF (or BK/BF) screw-support family. The bottom is the **floating** end: radial load only, free to slide as the screw grows, which is what makes it the cheap one. It needs **P32_ScrewFoot** to bolt to | 6 |
| D8a | **6001-2RS bearing** (12 × 28 × 8) | 1 | **Covered by the 6001s already bought**, which K3 no longer needs now the knee runs on 6904s. The screw's **upper** end. This line used to be a second KP08 bolted to "the drive bracket's screw boss" — [`420_mockup_audit.py`](../scripts/420_mockup_audit.py) went looking for the boss and found the bracket was **air at every Y from 210 to 296** along the screw axis: there was no boss, no bolt pattern, and nothing supporting the screw's top at all, so the screw was a cantilever off its bottom block. It is now seated in the **motor plate itself**, a ⌀22 × 7 pocket at Y 223…230. It does not get a boss of its own just above the nut's travel, where it would rather be: at Y 190 the bracket is a U-channel living at X ≥ −45 and a boss there attaches to nothing. One plate holding the motor and the screw's upper bearing is what the aluminium bracket did too. **Bond it, do not press it**. **Now a 6001-2RS (12 × 28 × 8) in a ⌀28 × 8 pocket**: the bought screw's fixed end is a ⌀12 × 25 bearing journal, long enough to carry the 20T pulley and the bearing together exactly as 433 drew it — but only if the ⌀10 tip and the M12 thread are parted off, which is Path B of [`446_sfu1605_set.py`](../scripts/446_sfu1605_set.py). Used as designed, **BK12 (in the box) replaces this line entirely** and the belt plane climbs 37 mm. The ⌀8/608 pairing came from the model's invented journals | 3 |
| D4a | **M5 × 16 motor bolts** | 4 | The C6374 to the drive bracket's end plate, on a **25 mm square** about the shaft. ⌀5.2 clearance takes M4 or M5. **MEASURE YOUR MOTOR FIRST**: 19 mm and 30 mm patterns exist on motors sold under similar names, the model's motor is a featureless cylinder, and nothing in CAD can confirm the spacing. Until 428_motor_mount.py the motor had no bolts at all and 420's hole count was satisfied by the KX-1 interface's four M4, 56 mm away on another face | 2 |
| D9 | Flexible shaft coupler — **IN THE BOX, unused** | 1 | It ships with the screw set for a coaxial stepper. The motor here is belted, so this is a spare. Do not design it in: a coupler on the ⌀10 tip puts the motor in line with the screw and 404/433 both rejected that | 0 |

## 3. Knee transmission

| # | Part | Qty | Notes | ~USD |
|---|---|---|---|---|
| K1 | HTD-8M **open-ended** belt, 30 mm wide, **1 metre** | 1 | **Cut to length on the machine.** The path is 2π·36.923 + 2·255 = 742.0 mm; 64 mm of that is clamped teeth and the rest is spare. Open-ended 8M is sold by the metre and stocked everywhere, where a 744 mm × 30 mm closed loop is a special order — and cutting it removes the quantisation: **a bought loop arrives 2.0 mm long** and the idler has to swallow 1.0 mm of centre distance out of the spring's 3 mm of travel. **The gantry already is the clamp**: the belt tunnel's inboard wall carries toothed grooves the belt's own teeth sit in, so going open-ended lengthens that channel from 5 grooves to 8 and adds a lid — **6 teeth for the 914 N tight end, 2 for the 150 N slack end, at the same 153 N/tooth and 1.5 MPa the design already accepts** ([`448_open_belt.py`](../scripts/448_open_belt.py)). The one thing given up is that a loop has no termination to fail. Previously, and this is the reasoning it replaces: a closed loop, not an open strip — no end terminations, and it is tensioned by sliding the idler instead. 764 N differential over 30 mm = 25.5 N/mm. **This length is only right because [`421_pulley_teeth.py`](../scripts/421_pulley_teeth.py) corrected the capstan**: the rim was built at 35.552 — the pitch line differential deducted twice — which puts the path at 737.7 mm, so a 742 mm belt would arrive 4.3 mm long against an idler with 3 mm of travel. The belt is gripped by a 5-tooth land in the gantry's tunnel, not clamped: see §5 and [`424_belt_tunnel.py`](../scripts/424_belt_tunnel.py) | 25 |
| K2 | **⌀20 × 70 hardened ground linear shaft, h6** | 1 | **⌀20, not ⌀12.** 457 sized this rod around a 6001 because BOM K3 and D8a were already 6001s — a parts-commonality argument that cost the shaft three quarters of its section. The printed capstan takes a 6904 with 14.3 mm of wall, so the bigger bearing was always available: **cantilever 94 MPa → 20**, the last acknowledged compromise in the joint. ⌀20 linear shaft is stocked by every 3D-printer and router supplier. Also the idler's axle. Previously ⌀12 × 60, and the reasoning below still applies to the shaft itself: **⌀20, not ⌀12, because the capstan became a bought pulley.** Its ⌀24 bore carries an 8 × 3.3 keyway reaching r 15.3, so the bearing seat must be bored past it whatever bearing goes in — and once you are boring, ⌀37 for a 6904 is the same cut as ⌀28 for a 6001. That takes the cantilever `457_knee_bearings.py` accepted from **94 MPa to 20**, the last acknowledged compromise in the joint. It is also the idler's axle. Previously ⌀12 × 60, and the reasoning below still applies to the shaft itself: The knee axis. **It is no longer a pin through a hinge — it is a stub axle.** The joint's bearings moved into the capstan ([`457_knee_bearings.py`](../scripts/457_knee_bearings.py)), so this rod is clamped in `P1_KneeYoke` over Z 76…94 (an 18 mm bonded ⌀12.2 bore plus an M4 grub through a heat-set insert) and cantilevers out through both 6001s. That deletes the two collar lines this entry used to need: the yoke IS the clamp. **h6 (0/−0.011), not the m6 of an ISO 8734 dowel** — m6 into a 6001's 0/−0.008 bore is an interference fit where this wants a hand assembly. **Not HSS**: hard and brittle, and this takes shock. Cantilevered it sees ~94 MPa; a ground rod carries that with a factor of ten | 8 |
| K3 | **6904-2RS sealed ball bearing** (20 × 37 × 9) | **4** | **Two in the printed capstan and two in the printed idler.** 69 N·m of tilt across a 21 mm span against the 6001 pair's 52, on a ⌀20 shaft instead of ⌀12, and the bond area 418 cares about goes from 704 to **1046 mm²** — the one job PETG has here gets easier. **Bond, do not press** — 418's rule stands for a plastic housing. Seat ⌀37.2 for a 0.1 mm bond line. A 6904 is a bike and RC shop part, stocked everywhere. The 6001s already bought are not wasted: D8a takes one. Previously 2 × 6001-2RS: **Two in the capstan and two in the idler**, which are now the same bought pulley (S2b), bored ⌀37. 76 N·m of tilt across a 23 mm span against the 6001 pair's 57, on a ⌀20 shaft instead of ⌀12. **Pressed into aluminium, not bonded into PETG** — 418's “a press fit into PETG does not hold” was about the plastic, not the fit. Seat 37 H7. The 6001s already bought are not wasted: D8a takes one. Previously 2 × 6001-2RS: **Two, and they are now inside the capstan** at Z 96…104 and Z 118…126 — flush to each face of the belt land, 22 mm apart, bonded into a ⌀28 seat with 6 mm of PETG wall and a ⌀26 abutment between them. The single one this line used to specify sat in the yoke at Z 80…88, **27 mm inboard of the belt it carried**: that offset is why `P2a_KneeHingePlate` spanned 58 mm and weighed 188 g to reach between load and support, and it turned the belt's 1064 N into a 28.7 N·m tilting moment taken by two printed bores. Centred, both numbers are zero and each bearing sees 532 N — a factor of 4.5 on C0, with ~52 N·m of tilt capacity across the pair. **A pair is the point**: one bearing cannot react tilt, and a self-aligning KFL/KP unit cannot either at any span ([`455_concept_rev2.py`](../scripts/455_concept_rev2.py)). **Bond, do not press** — 418's rule, and 532 N over π·28·8 mm² is 0.76 MPa. Same part as D8a | 6 |
| K4 | Compression spring, ~500 N/mm, 3 mm working travel | 1 | Now acts on the **idler carrier's slotted mount**, not a belt end. Same job — takes up belt bedding-in — one fewer printed part | 5 |
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

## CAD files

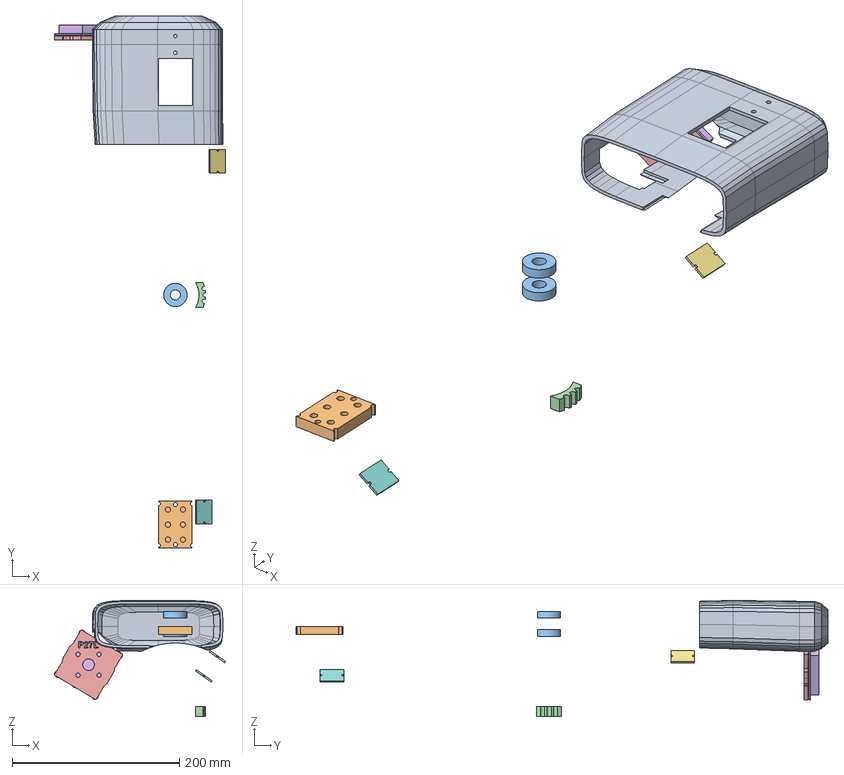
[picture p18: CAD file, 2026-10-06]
model/KneeExo_v8.FCStd
205.3 x 637.0 x 139.0 mm
P22_DriveCap
P31_InterfaceDist
HW_Bearing_6001_x2_KneePivot
TEST_ToothCoupon_3xHTD8M
P27_ControllerMount
HW_ODrive_XDriveMini
P28a_IMUCover
P28b_IMUCover

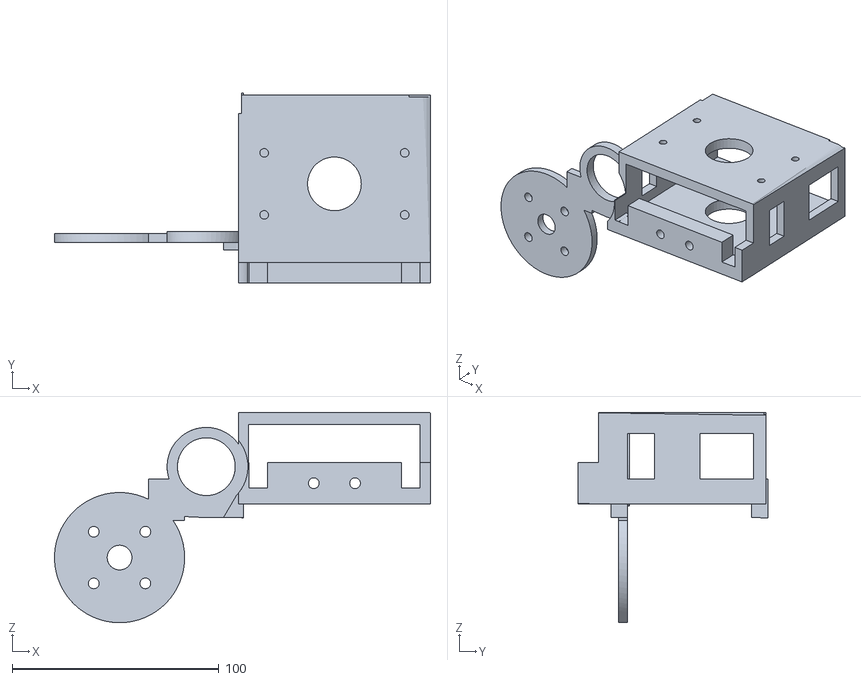
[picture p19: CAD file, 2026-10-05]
stl_v8/A7_DriveBracket_Idler.stl
182.0 x 92.0 x 101.8

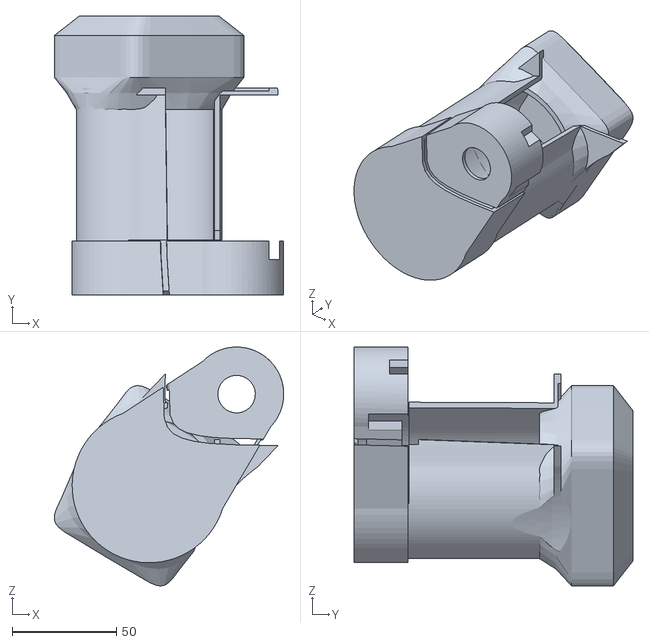
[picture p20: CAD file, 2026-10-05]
stl_v8/P25_MotorNacelle.stl
110.2 x 134.0 x 114.8

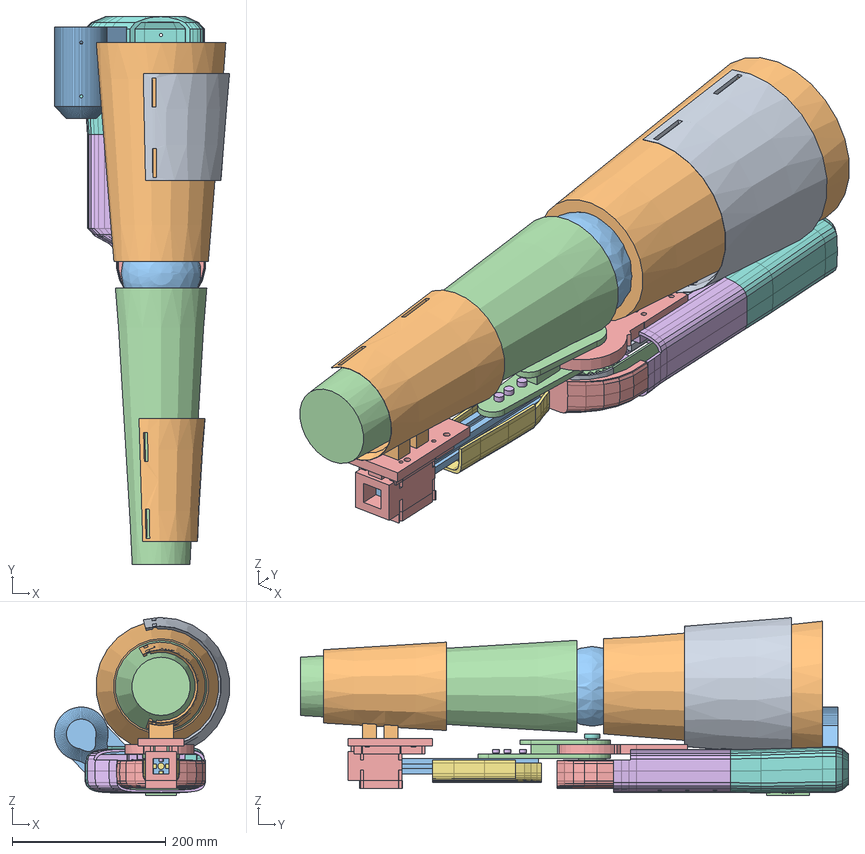
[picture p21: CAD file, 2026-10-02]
model/KneeExo_v6_R.FCStd
228.3 x 714.0 x 232.1 mm
A1_Extrusion_20x40_VSlot
REF_Thigh
REF_Knee
REF_Shank
P1_KneeYoke
P3_GantryPlate_Printed
A2_BallScrew_SFU1610
A3_Motor_C6374_170Kv
P5_ThighCuff
P7_ShankCuff
A4_Shank2020_VSlot
P2a_KneeHub_Pulley29T
P6_ShankSocket
HW_JointBolts
A2b_BallNut_SFU1610
HW_PinB_M12_KneePin
A5_Belt_WrapKnee_180
A5b_Belt_Strand_NegX
A7_DriveBracket_Idler
A5c_Belt_Strand_PosX
P20_KneeCap
P21_FairingThigh
P24_FairingShank
P22_DriveCap
A6_Idler_29T_HTD8M
A5d_Belt_WrapIdler_180
P10a_VWheel_Mini
P10b_VWheel_Mini
P10c_VWheel_Mini
P10d_VWheel_Mini
A7b_LinkBelt_1to1_HTD5M
P23a_FairingMount
P23b_FairingMount
P23c_FairingMount
P25_MotorNacelle
P30_InterfaceProx
P31_InterfaceDist
HW_Bearing_6001_KneePivot
TEST_ToothCoupon_3xHTD8M

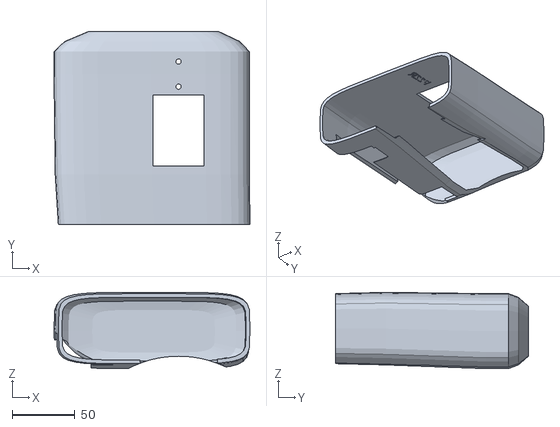
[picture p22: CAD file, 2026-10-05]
stl_v8/P22_DriveCap.stl
156.4 x 154.0 x 60.9

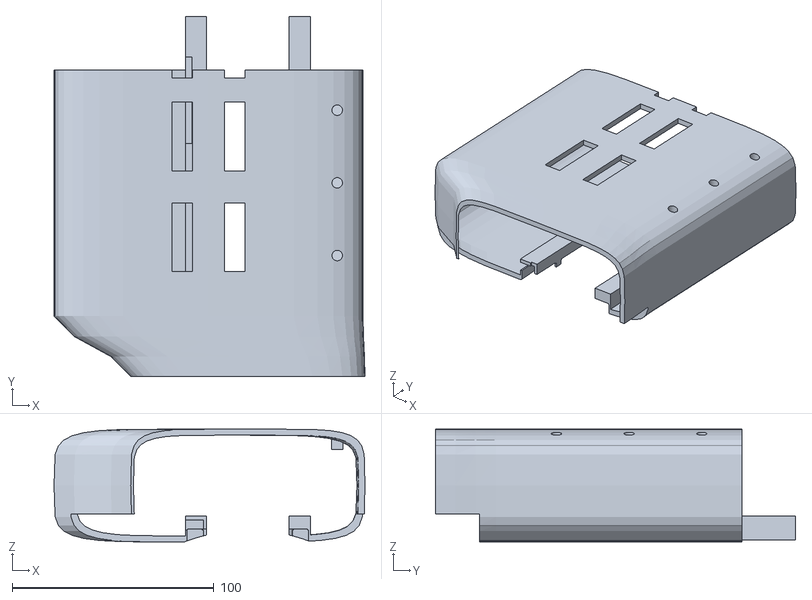
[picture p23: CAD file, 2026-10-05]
stl_v8/P21_FairingThigh.stl
154.0 x 178.5 x 55.9

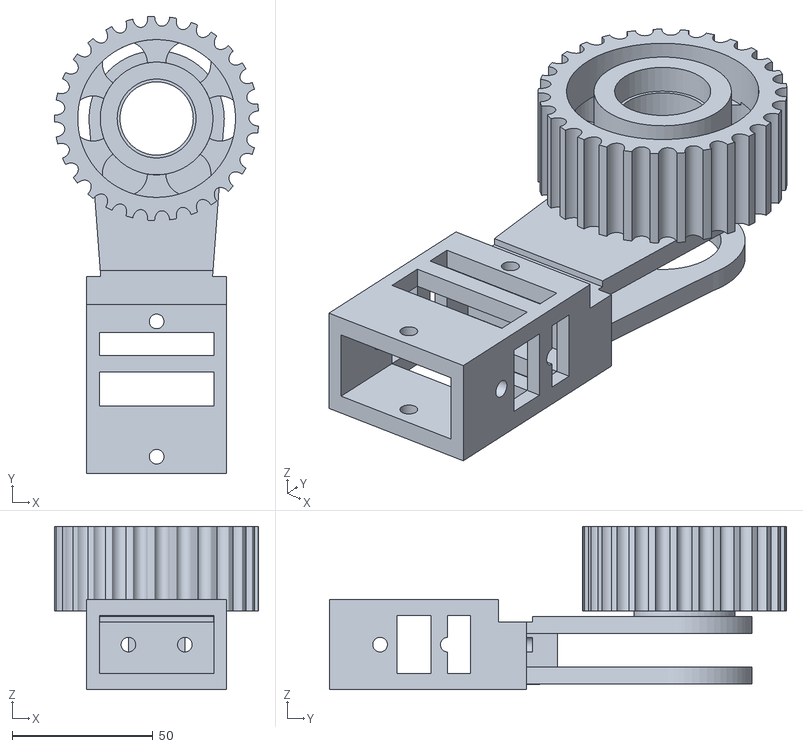
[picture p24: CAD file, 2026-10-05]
stl_v8/P2a_KneeHub_Pulley29T.stl
72.4 x 162.2 x 58.0

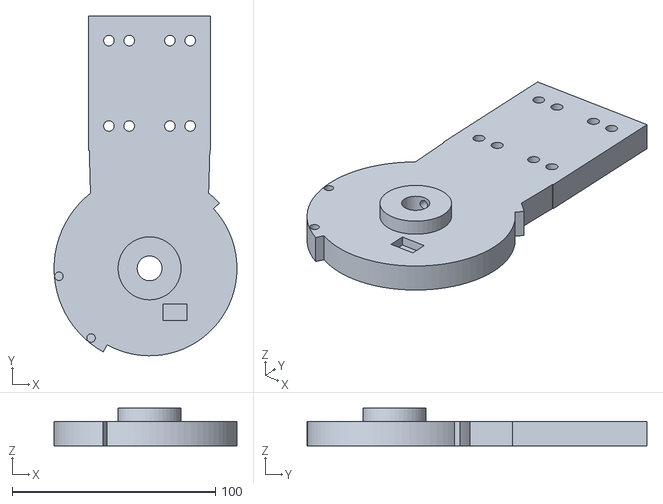
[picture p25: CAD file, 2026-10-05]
stl_v8/P1_KneeYoke.stl
90.0 x 167.0 x 18.5

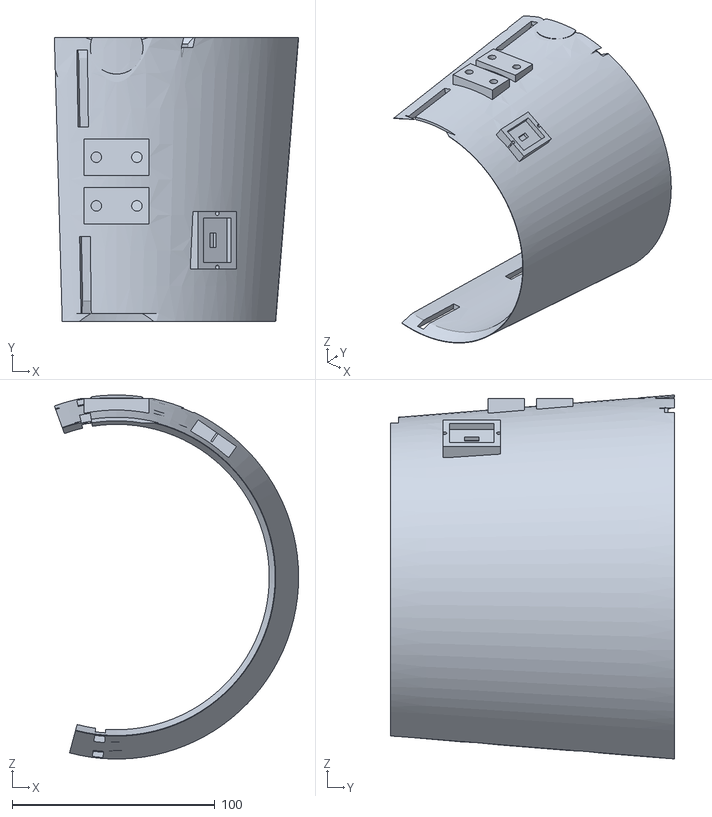
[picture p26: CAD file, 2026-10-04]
stl_v8/P5_ThighCuff.stl
120.5 x 140.0 x 179.5

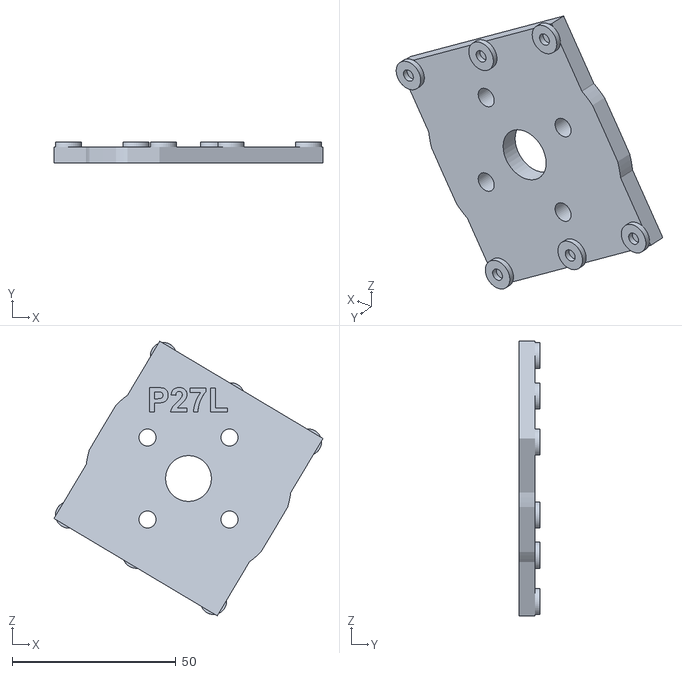
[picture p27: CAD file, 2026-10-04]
stl_v8/P27_ControllerMount.stl
82.1 x 6.50 x 83.8

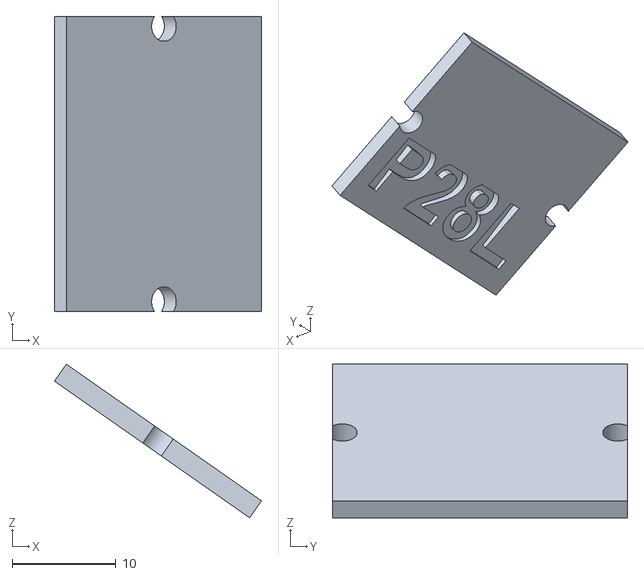
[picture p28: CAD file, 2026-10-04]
stl_v8/P28b_IMUCover.stl
20.0 x 28.5 x 14.8

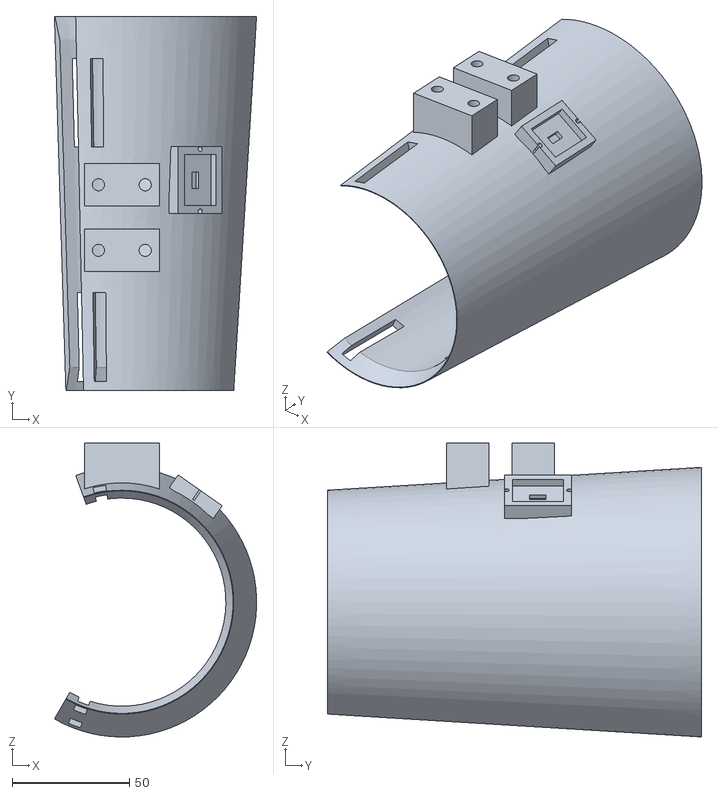
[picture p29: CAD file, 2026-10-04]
stl_v8/P7_ShankCuff.stl
86.4 x 160.0 x 125.6

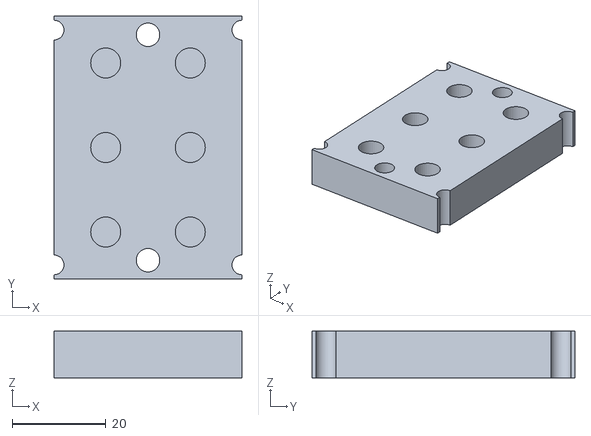
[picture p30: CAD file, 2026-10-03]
stl_v8/P31_InterfaceDist.stl
40.0 x 56.0 x 10.0

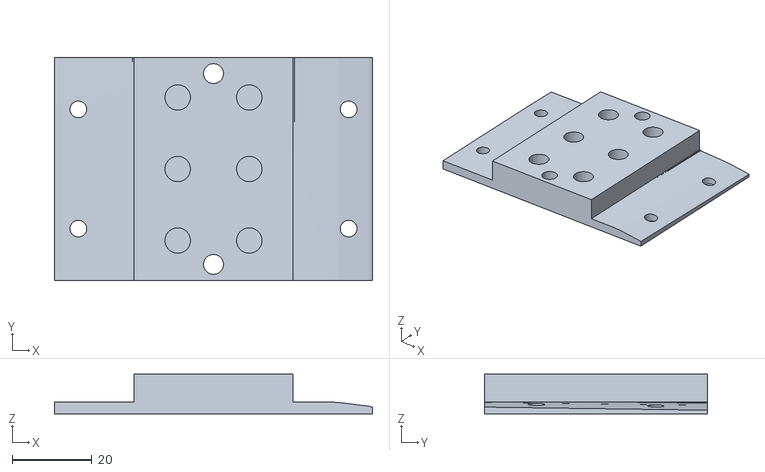
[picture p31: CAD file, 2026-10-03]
stl_v8/P30_InterfaceProx.stl
80.0 x 56.0 x 10.0

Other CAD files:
stl_v8/P28a_IMUCover.stl
stl_v8/P6_ShankSocket.stl
stl_v8/P3_GantryPlate_Printed.stl
stl_v8/TEST_ToothCoupon_3xHTD8M.stl
model/KneeExo_v6.FCStd
stl_R/A7_DriveBracket_Idler.stl
stl_R/P1_KneeYoke.stl
stl_R/P20_KneeCap.stl
stl_R/P21_FairingThigh.stl
stl_R/P22_DriveCap.stl
stl_R/P23a_FairingMount.stl
stl_R/P23b_FairingMount.stl
stl_R/P23c_FairingMount.stl
stl_R/P25_MotorNacelle.stl
stl_R/P27_ControllerMount.stl
stl_R/P28a_IMUCover.stl
stl_R/P28b_IMUCover.stl
stl_R/P2a_KneeHub_Pulley29T.stl
stl_R/P30_InterfaceProx.stl
stl_R/P31_InterfaceDist.stl
stl_R/P3_GantryPlate_Printed.stl
stl_R/P5_ThighCuff.stl
stl_R/P6_ShankSocket.stl
stl_R/P7_ShankCuff.stl
stl_R/TEST_ToothCoupon_3xHTD8M.stl
stl_v8/P20_KneeCap.stl
stl_v8/P23a_FairingMount.stl
stl_v8/P23b_FairingMount.stl
stl_v8/P23c_FairingMount.stl
stl_v8/P32_ScrewFoot.stl

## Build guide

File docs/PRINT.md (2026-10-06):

# Print list

**Generated by [`scripts/900_print_list.py`](../scripts/900_print_list.py) — do not edit by
hand.** Every number here is measured off the exported STLs in `stl/` and `stl_R/`; the mass and
time figures are models, stated below, and should be corrected against the first real print.

17 parts per leg, **34 for the pair**. They are not 15 parts printed twice: each one is chiral,
so a left part cannot be used on the right leg. The engraved number says which — `P5L` against
`P5R` — and that is the only thing distinguishing two parts that otherwise look identical.

## Settings

Blue PETG, 0.2 mm layers, 0.42 mm extrusion width. Per-part perimeters and infill come from the
load case, not from a global profile:

| Part | Perimeters | Infill | Why |
|---|---|---|---|
| `A7_DriveBracket_Idler` | 6 | 60% | holds the idler at 1828 N; the heaviest load path |
| `P1_KneeYoke` | 5 | 60% | carries the full knee reaction |
| `P20_KneeCap` | 3 | 15% | cosmetic |
| `P21_FairingThigh` | 3 | 15% | cosmetic |
| `P22_DriveCap` | 3 | 15% | cosmetic, but it is half the drive wall |
| `P23a_FairingMount` | 4 | 40% | carries the canopy |
| `P23b_FairingMount` | 4 | 40% | carries the canopy |
| `P23c_FairingMount` | 4 | 40% | carries the canopy |
| `P25_MotorNacelle` | 3 | 15% | cosmetic; prints nose-down on its domed end |
| `P27_ControllerMount` | 4 | 40% | carries the controller 2 mm off the shaft magnet |
| `P28a_IMUCover` | 3 | 20% | holds an MPU-6050 in its pocket; 2 mm, prints flat |
| `P28b_IMUCover` | 3 | 20% | the same lid again, on the shank cuff |
| `P2a_KneeHub_Pulley29T` | 6 | 60% | the 29T capstan; tooth flanks want a fresh nozzle |
| `P30_InterfaceProx` | 6 | 60% | KX-1 interface, 1.2 MPa of bearing standalone |
| `P31_InterfaceDist` | 6 | 60% | KX-1 interface, 1.2 MPa of bearing standalone |
| `P3_GantryPlate_Printed` | 6 | 50% | drags the whole gantry; in-plane loads only |
| `P5_ThighCuff` | 4 | 30% | pressure vessel, not a beam |
| `P6_ShankSocket` | 4 | 30% | structural but bulky |
| `P7_ShankCuff` | 4 | 30% | pressure vessel, not a beam |
| `TEST_ToothCoupon_3xHTD8M` | 6 | 60% | print FIRST and push a real HTD-8M belt into it |

## Per part, left leg

| Part | Orientation | Footprint | Height | Support | Volume | Est. filament | Est. time |
|---|---|---|---|---|---|---|---|
| `A7_DriveBracket_Idler` | +X up, 0° | 92 x 102 mm | 182 mm | 10.8% | 135 cm³ | 172 g | 10.7 h |
| `P1_KneeYoke` | -Y up, 0° | 90 x 12 mm | 167 mm | 5.8% | 125 cm³ | 127 g | 7.9 h |
| `P20_KneeCap` | +Y up, 0° | 116 x 36 mm | 74 mm | 8.8% | 31 cm³ | 39 g | 2.4 h |
| `P21_FairingThigh` | +Y up, 0° | 154 x 56 mm | 178 mm | 2.0% | 165 cm³ | 176 g | 11.0 h |
| `P22_DriveCap` | -Y up, 0° | 156 x 61 mm | 154 mm | 7.2% | 152 cm³ | 160 g | 10.0 h |
| `P23a_FairingMount` | +Z up, 0° | 27 x 16 mm | 39 mm | 12.7% | 6 cm³ | 8 g | 0.5 h |
| `P23b_FairingMount` | +Z up, 0° | 27 x 16 mm | 39 mm | 12.7% | 6 cm³ | 8 g | 0.5 h |
| `P23c_FairingMount` | +Z up, 0° | 27 x 16 mm | 39 mm | 12.7% | 6 cm³ | 8 g | 0.5 h |
| `P25_MotorNacelle` | +Y up, 0° | 110 x 108 mm | 133 mm | 9.9% | 98 cm³ | 120 g | 7.5 h |
| `P27_ControllerMount` | +X up, 0° | 6 x 84 mm | 82 mm | 5.6% | 18 cm³ | 21 g | 1.3 h |
| `P28a_IMUCover` | -Y up, 0° | 20 x 15 mm | 28 mm | 3.8% | 1 cm³ | 2 g | 0.1 h |
| `P28b_IMUCover` | -Y up, 0° | 20 x 15 mm | 28 mm | 4.5% | 1 cm³ | 2 g | 0.1 h |
| `P2a_KneeHub_Pulley29T` | -Y up, 0° | 72 x 58 mm | 162 mm | 13.6% | 148 cm³ | 188 g | 11.8 h |
| `P30_InterfaceProx` | -Y up, 0° | 80 x 10 mm | 56 mm | 6.6% | 27 cm³ | 34 g | 2.1 h |
| `P31_InterfaceDist` | +Y up, 0° | 40 x 10 mm | 56 mm | 9.9% | 20 cm³ | 25 g | 1.6 h |
| `P3_GantryPlate_Printed` | +Y up, 0° | 116 x 41 mm | 84 mm | 12.8% | 80 cm³ | 102 g | 6.3 h |
| `P5_ThighCuff` | -Y up, 0° | 120 x 180 mm | 140 mm | 0.9% | 163 cm³ | 197 g | 12.3 h |
| `P6_ShankSocket` | -Y up, 0° | 60 x 30 mm | 114 mm | 5.4% | 100 cm³ | 99 g | 6.2 h |
| `P7_ShankCuff` | -Y up, 0° | 86 x 126 mm | 160 mm | 2.4% | 138 cm³ | 161 g | 10.1 h |
| `TEST_ToothCoupon_3xHTD8M` | +Z up, 0° | 12 x 30 mm | 12 mm | 13.6% | 2 cm³ | 3 g | 0.2 h |
| | | | | **487 cm² total** | | **1651 g** | **103 h** |

The right leg is the mirror image and measures the same to within meshing noise: 
1422 cm³ against 1422 cm³, a 0.01% difference, all of it in facet placement.
So budget **3301 g of filament and 206 printer-hours for the pair**, plus supports.

## Before you assemble anything: holes

A printed hole comes off the bed 0.1–0.3 mm **under** its modelled size, and any hole whose axis
is not along the build direction prints as an egg. Almost every hole in this device runs along the
knee axis (Z) while most parts build along Y, so **assume every hole needs a drill pass**. Sizes
to finish to, from [`scripts/417_fastener_audit.py`](../scripts/417_fastener_audit.py):

| Modelled | Finish to | What it takes |
|---|---|---|
| ⌀4.2 | 4.3 | M4 clearance |
| ⌀5.0 | 5.0 H7 | locating dowel — ream, do not drill |
| ⌀5.2 | 5.3 | M5 clearance |
| ⌀6.4 | leave as printed | M5 heat-set insert, OD ~7.0, melted in |
| ⌀10.4 | leave as printed | cap head counterbore |
| ⌀12.2 | 12.2 | the knee rod's clamp bore in **`P1_KneeYoke`** — the yoke is the rod's only support now, so square in two planes, on a drill press. **The hub has no pin holes any more** |
| ⌀37 | 37.2 | the **two 6904 seats**, in `P2a` (the capstan) and again in `P2b` (the idler) — the same bearing in both, on the same ⌀20 shaft. Bonded, and **bore each pair in ONE setup**: they are the joint axis and separately-bored seats will not be collinear |
| ⌀28 | 28.2 | the 6001 seat for the **screw's upper bearing** in `A7_DriveBracket_Idler`. 28.2, not 28.0: the bearing is **bonded**, and that |
| | | 0.2 is the bond line. A press fit into PETG creeps and lets go within months |

| Part | Holes |
|---|---|
| `A7_DriveBracket_Idler` | 4 x M4 motor clearance, dia 20 clamp for the idler's axle, dia 28 x 8 seat for the screw's 6001 (bond), dia 9.2 screw bore, 2 x M5 along Y into the rail's end |
| `P1_KneeYoke` | 2 x M4 clearance, 4 x M5 into the rail at X +-10, 4 x M5 clearance for the canopy's lip at X +-20, 1 x dia 28 bearing seat (bore 28.2, bond) |
| `P20_KneeCap` | none |
| `P21_FairingThigh` | 19 x M5 clearance |
| `P22_DriveCap` | none |
| `P23a_FairingMount` | 1 x M5 clearance (on the build axis) |
| `P23b_FairingMount` | 1 x M5 clearance (on the build axis) |
| `P23c_FairingMount` | 1 x M5 clearance (on the build axis) |
| `P25_MotorNacelle` | none |
| `P27_ControllerMount` | 4 x M5 into the motor's rear, 4 x M3 into the board's bosses |
| `P28a_IMUCover` | 2 x M2.5 x 8 into the platform's bosses |
| `P28b_IMUCover` | 2 x M2.5 x 8 into the platform's bosses |
| `P2a_KneeHub_Pulley29T` | 3 x M5 clearance, 2 x dia 12.3 pin bore (clamped, not a journal), and 29 HTD-8M grooves on the dia 72.48 belt land |
| `P30_InterfaceProx` | 4 x M4 clearance, 2 x 5 mm dowel H7, 6 x M5 heat-set insert |
| `P31_InterfaceDist` | 6 x M4 clearance, 2 x 5 mm dowel H7, 6 x M5 heat-set insert |
| `P3_GantryPlate_Printed` | 4 x M5 V-wheel clearance, 2 x M5 radial set screws onto the ball nut, and the 5-tooth HTD-8M belt land -- the land prints as drawn and wants no reaming, but check it against the coupon |
| `P5_ThighCuff` | 4 x M5 clearance with cap head counterbores |
| `P6_ShankSocket` | 16 x M4 clearance, 4 x M5 heat-set insert |
| `P7_ShankCuff` | 4 x M5 clearance with cap head counterbores |
| `TEST_ToothCoupon_3xHTD8M` | see 417 |

## Where the supports are

Support fraction is of TOTAL surface area, so 10% is a few bosses rather than a disaster. What
matters is a part that cannot be oriented below the threshold at all. Measured, per part over 8%:

* **`A7_DriveBracket_Idler`** — 11% of its surface, 64.0 cm², overhangs past 45° in its best orientation
  (+X up, 0°).
* **`P20_KneeCap`** — 9% of its surface, 25.7 cm², overhangs past 45° in its best orientation
  (+Y up, 0°).
* **`P23a_FairingMount`** — 13% of its surface, 4.4 cm², overhangs past 45° in its best orientation
  (+Z up, 0°).
* **`P23b_FairingMount`** — 13% of its surface, 4.4 cm², overhangs past 45° in its best orientation
  (+Z up, 0°).
* **`P23c_FairingMount`** — 13% of its surface, 4.4 cm², overhangs past 45° in its best orientation
  (+Z up, 0°).
* **`P25_MotorNacelle`** — 10% of its surface, 73.9 cm², overhangs past 45° in its best orientation
  (+Y up, 0°).
* **`P2a_KneeHub_Pulley29T`** — 14% of its surface, 82.5 cm², overhangs past 45° in its best orientation
  (-Y up, 0°).
* **`P31_InterfaceDist`** — 10% of its surface, 7.5 cm², overhangs past 45° in its best orientation
  (+Y up, 0°).
* **`P3_GantryPlate_Printed`** — 13% of its surface, 46.8 cm², overhangs past 45° in its best orientation
  (+Y up, 0°).
* **`TEST_ToothCoupon_3xHTD8M`** — 14% of its surface, 2.1 cm², overhangs past 45° in its best orientation
  (+Z up, 0°).

The three fairing mounts are one part printed three times, and 4.0 of their 4.4 cm² is in the
first 4 mm above the bed: that is the bracket's foot, a flat underside. Printed on that face
the support disappears — the orientation search cannot see it, because it scores angles and a
flat underside at the bottom of a part is an angle like any other.

For the rest, the cause is not diagnosed here. The figures above say where to look in the
slicer; they do not say what the geometry is doing, and this file is generated, so it should not
guess. An earlier version of this script asserted the fairing mounts' explanation for every part
over 10%, which made it wrong about `P25_MotorNacelle` and `P2a_KneeHub_Pulley29T`.

## The models

The mass model is shell-plus-infill: shell = perimeters × 0.42 mm per side, and any part whose
mean wall (2V/A) is thinner than two shells prints effectively solid regardless of infill. The
time model is volumetric: 3.5 mm³/s of effective flow, which is 0.2 mm layers at 0.42 mm width
and 60 mm/s, derated for travel and acceleration. Neither has been checked against a real print,
because nothing has been printed yet. Correct them here once something has.

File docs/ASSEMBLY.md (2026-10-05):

# Assembly

Written to be followed with the parts in front of you, in the order they go together. Every printed
part carries its number engraved on a hidden face — `P5L` for the left leg, `P5R` for the right —
which is the only way to tell apart the two cuffs, the two halves of the drive shell and the three
identical fairing mounts once they are off the bed.

> [!WARNING]
> This is a **powered** device applying up to **28.2 N·m** to a post-operative knee. Two things are
> not optional: the side-release buckles in the strap loop (S5c), so the whole thing comes off in one
> squeeze, and a bench run through the full range of motion with the limb **out** of it before it
> goes on anybody. There is no FEA behind any printed part — only hand calculations
> ([`400_bracket_stress.py`](../scripts/400_bracket_stress.py),
> [`401_vwheel_load.py`](../scripts/401_vwheel_load.py),
> [`408_cuff_loads.py`](../scripts/408_cuff_loads.py)) and a 107-pose interference sweep.

Do not mix legs. The two sets are mirror images, not duplicates: a left shell will appear to fit the
right leg and will put the drive on the wrong side of the limb.

---

## 0. Before anything fits: finish the parts

Printed holes come off the bed 0.1–0.3 mm undersize, and in this device almost every hole runs
along the knee axis while most parts build along their length — so most holes print slightly oval
as well. Budget an hour per leg for this and do all of it before you pick up a bolt.

| Do this | To these |
|---|---|
| Drill 4.3 | every ⌀4.2 — `P1`, `P6` (16 of them), `P30`, `P31` |
| Drill 5.3 | every ⌀5.2 — `P1` (4, at X ±10), `P2a`, `P3` (4 wheel + 2 set screws), `P5`, `P7`, `P21` (19), `P23a/b/c`, `P6` (12 clamp bolts at |X| 24 + the cap's 2 axial), `P27` (4 into the motor's rear), `A7` (2 into the rail's end) |
| **Ream** 5.0 H7 | the ⌀5.0 dowel holes in `P30` and `P31` — these set the interface alignment, so ream, do not drill |
| **Bore 28.2, on a drill press** | the **two** ⌀28 bearing seats in **`P2a`**, at Z 96…104 and Z 118…126. 28.2 rather than 28.0 deliberately: the 6001s are **bonded**, not pressed, and 0.1 mm is the bond line. **Bore them in one setup without moving the part** — they are the knee axis, and two seats bored separately will not be collinear |
| Ream 12.2, on a drill press | the ⌀12.2 rod bore through **`P1_KneeYoke`**, Z 76…94. The yoke is now the rod's only clamp, so a crooked bore is a knee that points the wrong way. **The pin holes in `P2a` are gone** — the hub no longer touches the rod |
| Melt in M5 heat-set inserts | the ⌀6.4 holes — 4 in `P6`, 6 each in `P30` and `P31`. Leave the holes as printed; an M5 insert is ⌀7.0 and wants 6.4 |
| Leave alone | the ⌀10.4 counterbores on `P5` and `P7` — the cap heads sit in them |

Then dry-fit the knee: the rod through `P1L`, both 6001s dropped into `P2aL` **not yet bonded**, no
belt, and swing it. It must move freely through **−2° to +104°** with no tight spot. Fix that here,
not later: once the bearings are bonded in, getting back out of the seats means destroying them.

Full table: [`scripts/417_fastener_audit.py`](../scripts/417_fastener_audit.py), 136 holes.

---

## 1. Thigh spine and gantry

1. Cut the **20×40 V-slot** (S1) to **156 mm**, which is Y 51…207 on the model's axis. Deburr the
   slots or the T-nuts will not slide.
2. Fit the four **mini V-wheels** (S2) to the **gantry plate** (`P3_GantryPlate_Printed` — printed,
   not aluminium: [`802_no_metal.py`](../scripts/802_no_metal.py) puts it at 1.5–7.6 MPa in PETG),
   two on eccentric spacers. The four M5 bolt holes **are** drawn now, at |X| 23.36, Y 126 and 196
   ([`424_belt_tunnel.py`](../scripts/424_belt_tunnel.py) takes them from where the wheels actually
   sit rather than from a remembered number). Wheels sit on the |X| 20 corners, **70 mm apart in
   Y**, not 50: the Hertz contact at 50 mm is 107 MPa against a ~101 MPa yield onset
   ([`401_vwheel_load.py`](../scripts/401_vwheel_load.py)).
   **Mini wheels only.** A solid V-wheel reaches |X| 37.6, inside the belt's backing at 36.24…38.46;
   a mini reaches 31.0 and clears the belt's tooth tips at 32.86 by 1.86 mm.
3. Slide the plate onto the extrusion and set the eccentrics until it rolls with no rock and no
   drag. Check again after the belt is tensioned — tension changes it.
4. Mount the **ball screw** (D1, SFU1610 RH, **180 mm**) on its axis at **X = −62**: the **KP08** (D8)
   at the lower end, and at the upper end a **608-2RS bonded into the motor plate's ⌀22 × 7 seat**
   at Y 223…230 (D8a). The screw now stops just above the nut's travel instead of running past the
   motor — see step 7. The nut (D3) is **flangeless and trapped axially** between two plates
   on the gantry, not clamped radially: a 36.4 mm bore through a 40 mm housing would sever it, and
   the load is along Y anyway.
   **File a flat on the nut** and lock it against rotation with the two radial **M5 set screws**
   through the gantry's outboard wall at Y 149 and 173: trapping the nut axially carries the
   thrust, but a flangeless nut in a round pocket has nothing stopping it turning with the screw,
   and if it turns, the carriage does not move.

> The screw is **right-hand on both legs**. Do not look for a left-hand one for the right leg — the
> reflection is absorbed by one sign in firmware (section 9).

## 2. Drive bracket, motor, link belt

5. Bolt the **drive bracket** (`A7_DriveBracket_Idler` — printed, 6 mm plates) to the top of the
   extrusion: **two M5 × 16 along the limb** (S3a) through its 10 mm end plate at X ±10, Z 98,
   into the two cell cores in the rail's end face. Self-tapping into the core, or tap it. These
   holes did not exist until [`427_rail_bolts.py`](../scripts/427_rail_bolts.py) — the bracket that
   carries 1828 N had no M5 anywhere in it.

   **Bond the two idler bearings into their ⌀26 seats first**: a bare 10 mm axle through 6 mm of
   PETG is 15.2 MPa and will bed in, where the bearing's race spreads the same 914 N to 5.9. That
   substitution is what lets this part be printed at all. It carries three things: the 29T idler,
   the screw's upper bearing, and the motor.
6. Fit the **29T HTD-8M idler** (S2b) on the centreline at **X 0, Y 255**, supported top and bottom.
   Its axle reaction is up to **1828 N — the largest single load in the machine**, so both bearings,
   both ends, no exceptions.
7. Mount the **C6374 motor** (D5) **shaft down the limb** — turned over, hanging off the bracket's
   motor plate at Y 223…231, body Y 231…305 — with the **32T** pulley, and the **20T** on the screw.
   That is a **1:1.6 overdrive**, not 1:1 — it is what puts the total ratio at 14.5:1
   ([`404_link_ratio.py`](../scripts/404_link_ratio.py)). Close the **HTD-5M 15 mm** link belt (D6)
   over them at 61 mm centres, **under** the motor at Y 208…223, 5 mm clear of the carriage's
   proximal end at rest. **15 mm wide, and the CAD had it as 12** until
   [`433_drive_flip.py`](../scripts/433_drive_flip.py) rebuilt it to BOM D6 — which is why every
   Y above the belt moved up 3 mm from the first revision of this step.

   > **The link belt used to be on top, at Y 302…314, and the motor the other way up.** Turning the
   > motor over is what took the screw from 257 mm to 175 mm — 82 mm of SFU1620 that existed only
   > to reach a pulley above the motor, about **124 g** of steel off the thigh
   > ([`433_drive_flip.py`](../scripts/433_drive_flip.py)). It also frees the motor's rear end,
   > which is the only space in the pack the controller fits in.

7a. Bolt **`P27_ControllerMount`** to the motor's **rear bolt circle** (its face at Y 305) (4 × M5, same square as the
   front) and sit the **ODrive-clone XDRIVE MINI** on its four bosses. The board's **AS5047P** then
   looks straight down the motor's own shaft stub at the **⌀6 × 2.5 diametric magnet** (D5's
   magnet, BOM line D5) bonded to the shaft end:

   | surface | Y |
   |---|---|
   | shaft end | 307.0 |
   | magnet's outer face | 309.5 |
   | board's sensor face | 311.5 |

   → a **2.0 mm air gap**, inside the AS5047P's 0.5…3.0 mm. The mount is built to that chain, not
   to a stack-up guess ([`434_odrive_mount.py`](../scripts/434_odrive_mount.py)).

   > **MEASURE THE BOARD FIRST.** Every XDRIVE MINI dimension in the CAD — 63 × 58 outline, a
   > 55 × 50 M3 pattern, 10 mm of component height — is **guessed**. No mechanical drawing for this
   > clone is published anywhere, and the AS5047P's position on it decides whether the sensor sits
   > on the shaft's axis at all. The mount is a 20-minute reprint; the magnet bond is not.
8. Fit `P30L` (**KX-1 proximal interface**) to the bracket's top plate on its 4 × M4, with the
   6 × M5 inserts and 2 dowels facing out. It is the module interface; it does nothing in a
   single-knee build except exist for the next one.

## 3. Knee joint

9. `P1L_KneeYoke` to the lower end of the thigh spine, on **four M5 T-nuts at X ±10**, Y 70 and
   112. **Not six at X −20/0/+20** — that was the 20×60 rail's slot spacing and this is a 20×40;
   those six holes are filled. If you are working from an older print, check before drilling.

   `P2aL_KneeHub_Pulley29T` is the shank-side capstan and the 29T the main belt wraps — handle its
   tooth flanks carefully, they are printed, and they are an approximation of the HTD-8M form until
   the coupon says otherwise.
10. **Bond BOTH 6001s into `P2aL`** (K3, two off) — one at Z 96…104, one at Z 118…126, flush to
    each face of the belt land. Structural methacrylate or epoxy, each square to its face, wiped
    clean, left to cure before anything loads it. Do **not** press them in: PETG creeps under
    hoop stress and the interference is gone within months. **They are 22 mm apart and that span
    is what resists varus/valgus** — a bearing sitting cocked in its seat spends the span.
11. **The knee rod** (K2, ⌀12 × 60 ground) into `P1L`'s bore, Z 76…94, bonded, with the M4 grub
    through its heat-set insert as the mechanical backup. **It is a stub axle, not a pin**: the
    yoke is its only support and it cantilevers through both bearings. Set its depth so it ends
    at Z 130 — 1.5 mm short of `P20`'s inner face — and check it is square in two planes before
    the bond goes off. Nothing about the device is right if this is not square.
12. Swing the joint again, now loaded by the yoke: −2° to +104°. It should feel **free** — that is
    the point of the bearing. If it drags, the bearing is cocked in its seat or the pin is bent.

## 4. The main belt

13. **Thread** the **HTD-8M closed loop** (K1, 742 mm / 93T) through the gantry plate's belt tunnel
    first, then take it over the knee capstan and the idler. There is nothing to clamp and no belt
    end to terminate: the tunnel's inboard wall carries **five HTD-8M grooves at 8 mm pitch** over
    Y 144…186, and the belt's own teeth sit in them — the outboard wall at X −38.70 stops it
    backing out of mesh, the floor and roof stop it climbing. Slide the belt along until the teeth
    seat in all five grooves. The tooth phase sets the carriage's home position to within half a
    pitch, which is absorbed by homing. The loop is what makes **one** screw do both directions.
14. Tension it **by sliding the idler on its slotted mount** (K4's spring takes up bedding-in).
    The capstan loop carries up to **764 N** differential at peak torque over a 30 mm land; at the
    tunnel that is 153 N on each of the five teeth, 1.5 MPa across a 30 × 3.45 mm groove wall.
    Tension to the belt's spec, not by feel — this is the one place a slack belt looks fine and
    loses position under load.
15. Re-check the eccentrics (step 3) and run the gantry end to end by hand. **68.3 mm of stroke**,
    no binding, no belt climb.

## 5. Shank side

16. Cut the **20×20 V-slot** (A4) for the shank and clamp `P6L_ShankSocket` to it — 16 × M4. This is
    the part that transfers everything into the calf.
17. Fit `P31L_InterfaceDist` under `P6L` on its 6 × M4, dowels first. Its number is engraved on the
    **underside**, which beds on `P6L`: that is deliberate, it was the only covered face
    ([`413_mark_visibility.py`](../scripts/413_mark_visibility.py)).

## 6. Cuffs and the only parts that touch him

18. Put the **3 mm neoprene sleeves** (S5) on first, thigh and calf. They are the skin interface and
    a consumable. **Closed, dry incision only — ask whoever runs his rehab.** Neoprene contact
    dermatitis is common enough that a nylon-faced fallback is worth having on hand.
19. `P5L_ThighCuff` and `P7L_ShankCuff` on their 4 × M5 each. Both are **conical**, matched to the
    limb's taper, which is why they bear across their whole width at **12.5 and 12.2 kPa** instead of
    40 kPa on one narrow band ([`409_cuffs.py`](../scripts/409_cuffs.py)). They sit **4.00 mm** off
    the limb all over; that gap is the sleeve plus air, and it is uniform by construction.
20. Thread the **38 mm nylon webbing** (S5a) through the slots, **2:1 through the D-ring** into the
    cam buckle (S5b), with the **side-release buckle** (S5c) in the loop. Target **21 N** of strap
    tension with the neoprene on — about **12 N at your hand** through the 2:1. That is what holds
    the 3.52 N·m of roll torque the device's own mass applies.
21. **Practise the release.** Squeeze both side-release buckles; the whole device should come off in
    about two seconds. Do this before it is ever powered.

21a. **The two IMUs**, one into the pocket on each cuff's platform — thigh at Y 160, shank at
    Y −260, both on the +55° bearing — with `P28aL`/`P28bL` over them on 2 × M2.5 × 8 each.
    Run the cable out through the slot in the pocket's end.

    > **The pocket is the measurement.** Everything
    > [`441_posture.py`](../scripts/441_posture.py) computes — sitting against lying with the
    > knees up at 45°, standing against inverted at 180° — is an angle *in the sensor's own
    > frame*. The pocket's long axis runs along the limb, so the module's X is the segment's
    > axis and those numbers mean what they say. A module taped on at whatever angle the tape
    > allowed makes every one of them a guess, and the posture gate in ELECTRONICS §8a is
    > exactly as trustworthy as this step.

    Both modules go in **the same way up and the same way round**. Mark one corner of each
    before you fit them; "roll +180" is a real distinction and it is lost if one is flipped.

## 7. Fairings, last

22. `P23aL`, `P23bL`, `P23cL` into the extrusion's **posterior** side slot at Y 88, 124 and 160 —
    one M5 each, on rubber grommets (S4a), isolating rather than rigid. All three are the same part;
    they are interchangeable, which is why they share the mark `P23L`.
23. `P21L_FairingThigh` onto those three mounts, 19 × M5.
24. `P22L_DriveCap` and `P25L_MotorNacelle` — **these two are one wall split in two**, tiling the
    same shell with **zero overlap and no void between them**. P22 goes on first; the nacelle closes
    over the motor pod, and its proximal end now carries the **blister over the controller** — the
    nacelle no longer closes off at the motor's rear face, because that is where the board is
    ([`434_odrive_mount.py`](../scripts/434_odrive_mount.py)). Fit `P27L_ControllerMount` and the
    board (step 7a) **before** the nacelle goes on: there is no access to the magnet afterwards.
25. `P20L_KneeCap` over the knee. **There is no shank fairing.** `P24L_FairingShank` is deleted —
    the shank rail moved in-line under the knee joint, directly below the thigh rail, so it is
    behind the limb's own line and the socket wraps its proximal end
    ([`430_shank_inline_build.py`](../scripts/430_shank_inline_build.py)). Step 26 is what decides
    whether that is acceptable, not the fact that a fairing used to be there.
26. Check the cladding does what it is for: with everything on, no moving part should be reachable
    from the limb's side. That is verified in CAD at three poses with 187 rays
    ([`406_coverage.py`](../scripts/406_coverage.py)) and takes thirty seconds to confirm with a
    finger.

## 8. Electronics

See [`ELECTRONICS.md`](ELECTRONICS.md). In short: XDRIVE MINI / ODrive, the motor's own Hall sensors
for commutation, and an encoder for joint position. Route the motor phases and the encoder cable
**apart**, and keep the encoder cable off the belt run.

## 9. The one thing that differs between legs

**Invert the joint direction sign for the right leg.** Both legs use a right-hand ball screw, so for
a given motor direction the nut travels the same way — which means the knee goes the opposite way:

| | +motor rotation | nut travels | knee |
|---|---|---|---|
| left | + | distal | **extends** |
| right | + | distal | **flexes** |

One constant, in one place — the joint direction in firmware, or the axis map in the gait
controller. Getting this wrong drives the knee the wrong way under a 28.2 N·m assist, which is not a
subtle failure. [`700_handedness.py`](../scripts/700_handedness.py).

## 9a. Before the leg: the bench rig

Do this with the motor on the bench, not on him. [`440_bench_rig.py`](../scripts/440_bench_rig.py)
prints four parts that bolt the 6374 flange-down to a plate, put the magnet on the shaft end that
comes through it, and face the controller at it from a second plate on pillars. Nothing in it
depends on the motor having a stationary rear face — which is the exo's biggest unverified
assumption, and this is what settles it.

Three numbers come out of that session, and all three are things the CAD currently guesses:

1. **Does the 6374 have a usable stationary rear face at all?** If it does,
   `P27_ControllerMount` is right. If the rear is the rotating can, the controller has to hang
   off a cage from the front flange instead and §2's step 7a changes.
2. **The motor's bolt pattern.** The rig's eight radial slots take any square from 17 to 31 mm,
   so one print fits; measure what it actually is and put it in the BOM.
3. **The recess from the board's mounting face down to the AS5047P**, through the window in its
   backplate. That sets the air gap and nothing can derive it — the rig prints the arithmetic.

## 10. First power

In this order, with the limb out of the device:

1. ODrive motor and encoder calibration, device clamped to a bench.
2. **Unpowered** full-ROM sweep by hand. Listen for the belt and feel for a tight spot.
3. Powered, current limited to a quarter: command 10° steps across the whole range.
4. Full current, no limb, full range, and watch the knee axis for wander.
5. Only then, on the limb, with the straps at step 20's tension and a hand on the release.

---

## What is not verified

Honest list, so it is not discovered at the bench:

- **No FEA.** Hand calculations and a 107-pose interference sweep. The printed parts have margins
  computed by hand, not by simulation.
- **Nothing has been printed yet,** so the filament and time figures in [`PRINT.md`](PRINT.md) are
  models, and no hole has been tested against real hardware.
- **The motor's hip clearance is measured against nothing** — the reference limb model ends at the
  hip (Y = 300) and the motor sits there. Check it on the patient before printing the shells.
- **Acoustics are unmeasured.** Ball nut recirculation around 290 Hz is the likely source and the
  fairing the likely radiator. [`ELECTRONICS.md`](ELECTRONICS.md) §9.
- **Belt tooth-shear figures come from continuous-duty ratings** that carry high-speed fatigue
  derating. A slow capstan can run closer to the cord limit; check the actual belt's data.

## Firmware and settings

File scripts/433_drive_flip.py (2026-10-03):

# -*- coding: utf-8 -*-
"""Turn the motor over so its shaft points down the limb, and take 90 mm out of the ball screw.

Asked at the bench: "wouldn't it make more sense to invert the motor upside down and shorten the
screw a bunch". Measured before building, and yes:

    screw as drawn              Y 57..314 = 257 mm
    thread the nut actually uses   Y 73..183
    shaft above the nut's travel          131 mm, carrying torque and nothing else

The screw is that long only because the link belt sits on TOP of the drive, at Y 302..314, so the
screw has to reach up past the motor to meet it. Turn the motor over and the belt moves to the
motor's other end, below it, and the screw stops just above the nut.

THE STACK, FROM THE BOTTOM, AND WHY EACH NUMBER IS WHAT IT IS

    Y 203     the carriage's proximal end at rest. It only ever retreats from here, so this is
              the hard floor for anything fixed to the frame.
    Y 208-220 the link belt and both pulleys, 12 mm wide, 5 mm clear of the carriage
    Y 220-228 the motor's mounting plate: the shaft passes through it into the pulley
    Y 228-302 the motor, turned over. Its body does not grow the envelope -- it was Y 217..291
    Y 302+    the motor's free shaft end, where the magnet goes, in the space the belt vacated.
              434_odrive_mount.py puts the controller there, which is the only place it can go.

    screw     Y 57..232, with the 608 seated in the motor plate at Y 220..227 and the 20T
              pulley at 208..220.  175 mm instead of 257: 82 mm less screw, about 124 g of
              steel off the thigh.  The 608 does NOT get a boss of its own at Y 190, where it
              would rather be -- see BRG_Y below for why that boss attaches to nothing.

WHAT THIS DOES NOT DO. P22_DriveCap still runs to Y 334, sized to cover a link belt that is no
longer up there; the nacelle's distal end is trimmed here only as far as the belt's new plane
demands.  434_odrive_mount.py reworks the nacelle's other end around the controller, and
406_coverage.py is the check that says whether the trimmed shell leaves anything reachable.

    freecadcmd.exe scripts/433_drive_flip.py
"""
import math
import os
import sys

import FreeCAD
import Part
from FreeCAD import Vector as V

DOCFILE = os.environ.get("KX_DOC", r"C:/Users/Josh/KneeExo_v6.FCStd").replace("\\", "/")
_BASE = DOCFILE.rsplit("/", 1)[-1]
try:
    doc = next(d for d in FreeCAD.listDocuments().values()
               if d.FileName.replace(chr(92), "/").endswith(_BASE))
except StopIteration:
    doc = FreeCAD.openDocument(DOCFILE)

M5 = 5.2
SCREW_X, SCREW_Z = -62.0, 106.0

# THE MOTOR STAYS WHERE IT IS, and this is where a swing was tried and abandoned.
# 437_leg_size.py found the drive end 0.9 mm off the BARE thigh at Y 299, so the 3 mm sleeve of
# BOM S5 does not fit under it, and the obvious fix was to swing the motor out about the SCREW's
# axis -- the one direction that does not change the belt's 60.8 mm centre distance, so the only
# one available without a tensioner. 4 degrees buys 4.1 mm and a bare can is clear of everything
# to 10 degrees.
#
# IT IS NOT THE MOTOR THAT IS TOO CLOSE. 438_limb_clearance.py measured which parts are actually
# inside the sleeve, and the motor has 1.6 mm, its mount 1.6, the board 4.1, the bracket exactly
# 0.0 -- every one of them clear. The offender is the COVER over the controller, 2.9 mm deep, and
# its cavity has 4.5 mm of slack over the board on that side: it was drawn deeper than it needs
# to be, not pushed there by the motor. Swinging the motor to fix a cover is the wrong lever, and
# it costs a great deal: the pod is wrapped concentrically around the can, so moving the can
# pierces the pod wall (12.8 cm3), re-centring the pod moves the seam it shares with P22, and
# re-centring it by fusing a new tube instead put 51 cm3 into a cosmetic shell.
#
# 434_odrive_mount.py flattens the cover's section instead. The swing remains the right answer if
# a tape measure on the patient ever says the whole drive end has to stand further off -- it is
# four lines and one constant, and the arithmetic is in 437.
MOT_X, MOT_Z, MOT_R = -104.0, 62.0, 31.5
# THE BELT IS 15 mm WIDE. BOM D6 says so and 404_link_ratio.py sized it so -- "15 mm, not 9:
# it now carries the overdrive, ~153 N tight side" -- and the solid in the document was 12 mm
# thick, which put the motor's plate 3 mm into the belt it was supposed to clear. Everything
# proximal of the belt therefore moves up 3 mm from where the first version of this file put it.
BELT_W = 15.0
MOTOR_Y = (231.0, 305.0)
PLATE_Y = (223.0, 231.0)
BELT_Y = (208.0, 208.0 + BELT_W)
# THE 608 GOES IN THE MOTOR'S PLATE, not in a boss of its own. A boss at Y 190 -- just above the
# nut's travel, which is where it wants to be -- attaches to nothing: the bracket is empty until
# Y 206. The plate carries the screw's axis anyway (its section spans X -135..+46), it is 8 mm
# thick and a 608 is 7 mm wide, and this is what the original bracket did at Y 291..299: one
# plate holding the motor and the screw's upper bearing.
BRG_Y = (223.0, 230.0)          # the 608, seated in the motor plate
SCREW_Y = (57.0, 235.0)
R_BODY, R_END = 7.90, 4.00
# thread to Y 204, then dia 8 through the pulley (208..220) and the bearing (220..227). The nut
# needs thread to Y 183 at the top of its stroke, so 204 clears it by 21 mm.
JOURNAL = (71.0, 204.0)
MOT_BOLT = 12.5                 # the 25 mm square, as 428 assumed -- measure the motor
CARRIAGE_LIMIT = 203.0

a3 = doc.getObject("A3_Motor_6374")
a7 = doc.getObject("A7_DriveBox")
a7b = doc.getObject("A7b_LinkBelt")
a2 = doc.getObject("A2_BallScrew_SFU1620")
assert a3 and a7 and a7b and a2, "missing the motor, bracket, link belt or screw"
mirrored = a7.Shape.BoundBox.ZMax < 0
sgn = -1.0 if mirrored else 1.0


def z(v):
    return sgn * v


def zspan(lo, hi):
    a, b = z(lo), z(hi)
    return (min(a, b), max(a, b))


print("=" * 98)
print("DRIVE FLIPPED  --  %s, %s leg" % (_BASE, "right" if mirrored else "left"))
print("=" * 98)
car = doc.getObject("P3_Carriage")
if car is not None:
    top = car.Shape.BoundBox.YMax
    print("  the carriage's proximal end is at Y %.1f; the belt starts at Y %.0f, %.0f mm clear"
          % (top, BELT_Y[0], BELT_Y[0] - top))
    assert BELT_Y[0] > top + 2.0, "the link belt would foul the carriage"

# ---------------------------------------------------------------- the motor, turned over
b3 = a3.Shape.BoundBox
a3.Shape = Part.makeCylinder(MOT_R, MOTOR_Y[1] - MOTOR_Y[0], V(MOT_X, MOTOR_Y[0], z(MOT_Z)),
                             V(0, 1, 0))
print("  motor Y %.0f..%.0f -> %.0f..%.0f, shaft now out of the DISTAL face at Y %.0f"
      % (b3.YMin, b3.YMax, MOTOR_Y[0], MOTOR_Y[1], MOTOR_Y[0]))
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

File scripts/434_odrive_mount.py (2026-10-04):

# -*- coding: utf-8 -*-
"""Put the controller in the machine. It has never been in it.

Forty-two solids in the model and not one of them electronic: the MKS XDRIVE MINI is ordered
(BOM E1, four owned), routed in ELECTRONICS's topology, and has no board, no mount, no standoffs
and no space reserved. It also cannot be put in the backpack with the battery, which is the usual
answer for a controller, because its AS5047P is ON the board and reads the 6 x 2.5 mm diametric
magnet glued to the motor's shaft (BOM D5). From the AMS datasheet:

    air gap, package face to magnet     0.5 to 3 mm
    magnet centred on the package       within 0.5 mm

So the board sits a few millimetres off the end of the motor's free shaft, concentric with it.
433_drive_flip.py turned the motor over, which left exactly that space empty: the link belt used
to occupy Y 302..314 and now runs below the motor instead.

WHAT IS ASSUMED HERE, ALL OF IT FLAGGED, because no mechanical drawing of this board is
published anywhere -- Makerbase's repository carries a schematic and nothing else, the community
notes have a drawing as a PNG with no dimensions, and the 63 x 58 mm that circulates in search
results is not corroborated by the page it is attributed to:

    BOARD           63 x 58 x 1.6, components 10 mm       UNVERIFIED -- measure yours
    BOARD_HOLES     55 x 50 rectangle of M3               GUESSED -- measure yours
    IC_OFFSET       the AS5047P at the board's centre     GUESSED, and it is the one that
                                                          matters: the IC is the datum, not the
                                                          outline, because it must sit on the
                                                          shaft's axis within 0.5 mm
    SHAFT_PROUD     2 mm of shaft past the motor's rear   UNVERIFIED
    REAR_BOLTS      the same 25 mm square as the front    UNVERIFIED -- 428 flags this too

Every one of those is a number that should come off the bench, and the mount is parameterised so
that correcting one and re-running is the whole job. What the file does guarantee is the thing
the datasheet fixes: it refuses to finish if the air gap it has built falls outside 0.5..3 mm.

    freecadcmd.exe scripts/434_odrive_mount.py
"""
import math
import os
import sys

import FreeCAD
import Part
from FreeCAD import Vector as V

sys.path.insert(0, os.path.join(os.path.dirname(os.path.abspath(__file__)), "..", "tools"))
import limbcone                                                     # noqa: E402

DOCFILE = os.environ.get("KX_DOC", r"C:/Users/Josh/KneeExo_v6.FCStd").replace("\\", "/")
_BASE = DOCFILE.rsplit("/", 1)[-1]
try:
    doc = next(d for d in FreeCAD.listDocuments().values()
               if d.FileName.replace(chr(92), "/").endswith(_BASE))
except StopIteration:
    doc = FreeCAD.openDocument(DOCFILE)

M5, M3 = 5.2, 3.2
BOARD = (63.0, 58.0, 1.6)       # UNVERIFIED
# SOURCED, NOT GUESSED, as of the "Size" drawing in Smurf/xdrive-mini-docs and a photograph of
# the board's encoder face. This used to read (55.0, 50.0) with a comment saying GUESSED, and it
# was wrong in both the spacing and the COUNT: there are SIX M3 holes, not four, in two columns
# of three, and the middle row is not centred.
#
#     board          63.00 x 58.00          (the drawing, and two vendor listings)
#     holes          dia 3.3 x 6
#     columns        56.60 apart            -> +-28.30, inset 3.20 from each edge
#     rows           51.50 corner to corner, the middle one 24.00 below the top and 27.50
#                    above the bottom -- so it sits 1.75 ABOVE the board's centre line
#
# The corner four are symmetric about the board's centre, which is what lets the sensor sit on
# the shaft axis with the board centred on them.
BOARD_HOLES = (56.60, 51.50)    # corner-to-corner, from the published Size drawing
MID_ROW_UP = 1.75               # the middle pair, above the centre line
COMPONENTS = 10.0               # GUESSED, the tall side faces away from the motor
SHAFT_PROUD = 2.0               # UNVERIFIED
MAGNET = (6.0, 2.5)             # BOM D5, and what the datasheet asks for
AIR_GAP = 2.0                   # target, inside the datasheet's 0.5..3.0
GAP_LIMITS = (0.5, 3.0)         # AS5047P
REAR_BOLTS = 12.5               # half of the 25 mm square -- UNVERIFIED
CAP_T = 5.0                     # the mount's own plate

mot = doc.getObject("A3_Motor_6374")
a7 = doc.getObject("A7_DriveBox")
assert mot is not None, "no motor in this document"
mb = mot.Shape.BoundBox
MOT_X, MOT_R = 0.5 * (mb.XMin + mb.XMax), 0.5 * mb.XLength
MOT_Z = 0.5 * (mb.ZMin + mb.ZMax)
REAR_Y = mb.YMax                # the free end, after 433 turned the motor over
mirrored = mb.ZMax < 0
sgn = -1.0 if mirrored else 1.0

print("=" * 98)
print("CONTROLLER MOUNT  --  %s, %s leg" % (_BASE, "right" if mirrored else "left"))
print("=" * 98)
print("  the motor's free shaft end is at Y %.0f, on the axis X %.0f Z %.0f"
      % (REAR_Y, MOT_X, MOT_Z))

# where everything lands, from the shaft outwards
shaft_end = REAR_Y + SHAFT_PROUD
magnet_face = shaft_end + MAGNET[1]
ic_face = magnet_face + AIR_GAP
board_y = (ic_face, ic_face + BOARD[2])
print("  shaft end Y %.1f -> magnet face %.1f -> board's sensor face %.1f (%.1f mm air gap)"
      % (shaft_end, magnet_face, ic_face, AIR_GAP))
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

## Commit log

2026-09-29 Knee orthosis: belt capstan with differential lead screws
    Parametric FreeCAD model of a powered knee orthosis targeting ~30% assist
    (28.2 N.m at 80 kg) over -2..104 deg.
    Current architecture: 29T HTD-8M capstan concentric with the knee pin, 180 deg
    wrap, both belt runs parallel to a 20x60 rail, driven by opposed RH/LH SFU1620
    screws on one shaft. The differential satisfies the belt's Ya+Yb=const exactly
    (verified constant at 242.00 mm over 107 poses), so no take-up spring is needed
    for motion -- only a 3 mm sprung anchor to hold pretension through bedding-in.
    Verified with a full pairwise interference sweep, no skip list: zero hard-part
    clashes across 107 poses.
    Includes the design histor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
    [KneeExo_v6.FCStd, P10a_Slider_Delrin.stl, P10b_Slider_Delrin.stl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]
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2026-09-29 Replace blocky guards with lofted fairings
    P20_KneeCap (closed nose over pulley + belt wrap), P21_FairingThigh (one canopy
    Y 28..312 over the whole drive), P24_FairingShank. Superelliptical sections at
    exponent 5.5 -- rounded rectangle, not a slab. Thigh fairing flares 58->84 mm
    half-width on a smoothstep, 8 vent slots, mounted on a central spine into the
    rail's middle outboard slot at X=0 (the one channel nothing else uses, so the
    mounts are never swept). Knee pin head recessed flush at Z=126.
    Enabled by the fact that the pulley's INSIDE is what swings: nothing moving
    occupies r 41..70 at Z 96..126, so the belt and pulley outer face can be fully
    enclosed by static covers.
    Three modelling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
    [KneeExo_v6.FCStd, P20_KneeCap.stl, P20_KneeShroud.stl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]
2026-09-29 Add Cycles renders: 8 views x 2 poses, black extrusion + blue PETG
    Headless Blender 5.0 on the rtx0 box (4x RTX 3060, CUDA), 512 samples with
    OIDN, AgX medium-high contrast, f/11 so the mechanism stays sharp.
    Materials keyed off the MAT__ filename prefix the STL exporter writes:
    black anodised aluminium for the 20x60 rail, deep blue PETG split into a
    structural grade and a smoother fairing grade, plus steel/ballnut/belt/
    Delrin/motor. Every surface carries a noise roughness break-up and a fine
    bump so nothing reads as injection moulding.
    Two poses: 40 deg flexion and full extension. Each pose is shot clad
    (fairings on) and open (fairings hidden) so the extrusion and the twin
    LH/RH screws a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
2026-09-29 Add build list, ODrive/electronics architecture, drivetrain sizing
    scripts/300_drivetrain.py derives every number the two documents quote, so
    there is one place to change an assumption.
    Two things fell out of it that change the build:
    1. Reflected rotor inertia goes as the square of the total knee->motor
    ratio, so the screw lead decides what the leg feels like with the power
    off -- 2.22x the limb's own inertia at 5 mm lead, 0.56x at 10 mm. You
    cannot fix it by moving the reduction around; only the total ratio
    matters. 10 mm is the right answer but its ball nut is OD 36 and fouls
    the belt at the current X = +/-58, so the screws need to move out to
    +/-62. Not yet modelled.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
2026-09-29 Rewrite README as a technical walkthrough; add flexion-cycle animations
    The README now follows the chain of decisions rather than listing features:
    the two numbers that set everything (28.2 N.m, -2 to 104 deg), the proof
    that the differential is exact rather than approximate, the four
    architectures that were built and measured before being dropped and the
    number that killed each, the drivetrain trade, the packaging limits, and
    the five modelling traps that each produced a plausible wrong answer.
    Animations: 222_anim_export.py sweeps a full flexion cycle on
    theta = 52 - 52*cos(2*pi*i/32), so 0 -> 104 -> 0 loops seamlessly with no
    duplicated end frame, and asserts the differential on every fr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
2026-09-29 Add FreeCAD viewport screenshots; make CAD the default illustration
    The README now shows the model itself for every technical point and keeps
    Blender for the hero shots, each labelled as a Cycles render so it is never
    mistaken for the geometry.
    New in renders/cad: a three-quarter pair (mechanism and clad on the limb),
    orthographic sagittal and frontal, a capstan detail, and a differential
    pair -- full extension and full flexion at identical camera and scale, so
    carriage A dropping 68.3 mm while B rises the same is visible directly
    rather than only asserted.
    Fixes a real bug the moment the reference limb became visible: REF_Shank
    was never posed by the export scripts, so the limb stood stra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
2026-09-30 Drop the knee cheek; extend the shank fairing instead
    The cheek swept clean but it is a 216 mm flat plate standing off the side
    of the knee -- ugly, and a snag hazard in its own right at exactly the
    height that catches a door frame, on a device meant to stop the patient
    catching on things. What it covered is bare structural plate, not
    mechanism: the nips are at the capstan and P20 already closes over both.
    Instead P24 gains a tapered proximal tip to Y = -66, taking the moving gap
    from 55 mm to 20 mm, which a fabric gaiter covers. P20 is back to stock at
    30.8 cm3. The drive cap stays -- nothing swings at the hip, and a spinning
    outrunner bell does want enclosing.
    Fixing the tip surfaced a r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
    [P20_KneeCap.stl, P24_FairingShank.stl]
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2026-09-30 Build the SFU1610: nuts at OD 36, carriages resized, swept clean
    The reflected-inertia analysis has wanted 1610 for a while -- 0.56x the
    limb's own against 2.22x for 1605 -- and 311_nut_belt.py removed the only
    stated obstacle. This builds it.
    Three changes, two of which only the 107-pose sweep found:
    * The carriage body grows to X 34..80, Z 84..128 to capture a 36 mm
    bore with a 3.8 mm wall on all three faces.
    * Its top-outboard corner then clipped P21 by 0.495 cm3 -- trap 2
    again, since a superellipse is not 84 wide everywhere and by Z=128
    its inner wall has come in to about 80.3. Bringing the screws to
    +/-56 fixed that but pinched the Hall board between the sprung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
    [P3_Carriage.stl, P3b_CarriageB.stl, P5_ThighCuff.stl]
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2026-09-30 Replace the Delrin gibs with MGN7H rails on the 20 mm side faces
    The guide reaction is 176 N, so capacity was never the question. Friction
    was: acetal on aluminium is sliding contact, ~70 N and 7.7% of belt pull,
    with stick-slip and a mu that wanders. Rolling takes it to 1.4 N, which
    matters for a device meant to deliver 10% assist smoothly.
    Side faces, rail centre Z = 98, block at Z 89.5..106.5 -- between the
    thigh cuff's Z 88 top and the extrusion's lateral face at 108, inside the
    carriages' existing envelope. No dimensional cost, and it leaves the
    lateral 60 mm face free, which the front-mounted screw layout would need.
    MGN7, not MGN9, because of 0.9 mm. The BLOCKS never share length wi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
    [P10a_Slider_Delrin.stl, P10b_Slider_Delrin.stl, P10c_Slider_Delrin.stl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]
2026-09-30 Keep the MGN7H rails; record the acoustics analysis and why wheels lost
    V-wheels were the better answer to noise on the face of it -- POM rolling
    on aluminium has no recirculation circuit -- but they ride the extrusion's
    outer corner V, and the land between two 20-series slots is ~10 mm of flat
    that a wheel groove bottoms out on before its flanks engage. On a 20x60
    the corners are at |X| 30 and the belt runs start at 35.55, so even a mini
    wheel fouls by 2.1 mm. The belt cannot move: it is tangent to the 29T
    pulley and that radius is the moment arm.
    320_rail_section.py works the alternative: a 20x40 puts the corners at 20
    and both wheel sizes clear. The section can afford it -- tip deflectio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
    [P3_Carriage.stl, P3b_CarriageB.stl]
2026-09-30 Audit: refresh the stale CAD file, correct stale claims
    The committed model/KneeExo_v6.FCStd was seven hours behind the live
    document -- it predated the SFU1610 nuts, the resized carriages, the drive
    cap, the shank tip extension and the MGN7H rails. The STLs and renders in
    the repo were current but the CAD that generated them was not, so a clone
    could not have reproduced them. Refreshed, re-saved unposed, Apache-2.0
    License property intact, 40 objects, all new parts present.
    Model audit: every Part object is a single valid closed solid with an
    identity placement. HW_JointBolts reports 3 solids, which is correct --
    it is three bolts.
    Numbers re-derived from the model and reconciled against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
    [KneeExo_v6.FCStd]
2026-09-30 Close the drive cap around the motor; LiFePO4 pack; tendon study
    The cap was open on its medial side below Z 92, following P21's convention
    -- right for a static canopy over the thigh, wrong over an outrunner,
    whose entire bell rotates. It left a 5.5 mm band of spinning case at
    Z 86.5..92 pointing at the leg. The cap now closes right round from
    Y = 310: motor 0.00 cm3 outside the envelope, 125.5 -> 175.9 cm3. It
    becomes a clamshell to assemble.
    Also fixes 223_cad_shots.py, which ended on a fairings-off shot and never
    restored visibility, leaving the document looking as though the motor had
    no cover at all.
    Battery: the bought pack is A123 LiFePO4 736 Wh with a 7-17S 100 A smart
    BMS. Three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
    [KneeExo_v6.FCStd]
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2026-09-30 Re-cladding: posterior side mounts, and the assembly now sweeps completely clean
    34 parts, 107 poses, ZERO hard-part clashes and ZERO cladding clashes. The only
    overlaps left are the reference limb's own solids and the cuff gripping the limb.
    Knee standoff unchanged at 86 mm proud.
    The fairing spine had to move, and I got where to twice wrong before measuring it.
    A 2040's 40 mm face has slots at X = +/-10 rather than 0, but the bigger problem is
    that the gantry deck sweeps X -32.5..32 over Y 59..197 and the idler spans
    X +/-35.55 over Y 213..291, so between them they own the rail's whole OUTBOARD
    face. From that I concluded there was no mid-span mount left and fell back to two
    end flanges s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
    [KneeExo_v6.FCStd, P11_SprungAnchor.stl, P21_FairingThigh.stl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]
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2026-10-01 Drive-end cover: one wall split into two parts, and the yoke collision the sweep had been carrying
    The ask was to keep the motor in its cover but make that cover coherent with the rest of
    the top of the leg. Merging the cap and the pod into one lofted section was the obvious
    answer and it is arithmetically impossible:
    motor axis 121.1 mm from the leg axis, can radius 31.5 -> can face at 89.6
    thigh surface + 3.0 comfort clearance -> 87.9
    room for a cover between them -> 1.7 mm
    The motor is tucked hard enough that its cover has to be a tight tube there. A section big
    enough for both lobes has its floor 60 mm below the hardware, and the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
    [KneeExo_v6.FCStd, P21_FairingThigh.stl, P22_DriveCap.stl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]
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2026-10-01 Every part number is now verifiably hidden, and the distal interface was never posed
    The user reported seeing part numbers on outside faces. They were right, and so was the
    follow-up that P31 was visible too. 412 placed each mark on "the first surface a ray from the
    limb axis meets" and called that an inner face. INNER SURFACE and HIDDEN are different
    properties and nothing was checking the second one.
    413_mark_visibility.py now asks the question directly: standing outside with the limb in
    place, is there a line of sight to the mark? Writing that test took four attempts and every
    wrong version reported a pass:
    1. Occluders included the GROUPS (C_Drive, B_Shank), whose Shape is a compound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
    [KneeExo_v6.FCStd, P1_KneeYoke.stl, P20_KneeCap.stl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]
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2026-10-02 Snapshot both legs into the repository: the tracked model was two commits stale
    model/ and stl/ held the parts from before the re-engraving -- the ones whose numbers
    were mirror images -- and nothing said so. The right leg and both mark registries were
    not tracked at all.
    model/KneeExo_v6.FCStd refreshed
    model/KneeExo_v6_R.FCStd new
    model/*.marks.json new, both legs
    stl/ 14 of 15 refreshed; P2a_KneeHub is byte-identical,
    which is the one part deliberately left unmarked
    stl_R/ new, 15 parts
    tools/snapshot.py does the copying and, without --write, reports what has drifted. The
    wor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
    [KneeExo_v6.FCStd, KneeExo_v6_R.FCStd, P1_KneeYoke.stl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]
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2026-10-02 No fabricated metal: the drive bracket and gantry plate are printed, and 241 g lighter
    "A7 won't be metal -- how am I supposed to fabricate that? The only metal is the motor, the
    bearings and the extrusion." Correct, and fabricated was a planning assumption rather than a
    decision. S2d and S2e were the only two parts needing a workshop; both print.
    Neither was ever sized by load. 400_bracket_stress.py already had the bracket 50x overbuilt at
    4.3 MPa against aluminium's 240, so in PETG the governing rule becomes creep and bearing
    rather than yield:
    bracket plates 6 mm 9.8 MPa bending
    idler bearing 6 mm 5.9 MPa, against 15.2 for a bare 10 mm axle, which beds in
    gantry pla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
    [A7_DriveBracket_Idler.stl, KneeExo_v6.FCStd, KneeExo_v6_R.FCStd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]
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2026-10-02 The pulley has teeth, the belt sits where a belt sits, and the gantry grips it
    420_mockup_audit.py found eight missing features across five of the seventeen printed parts.
    Fixing them moved three things that had been wrong for months and agreed with each other.
    THE CAPSTAN'S RADIUS WAS NOT A FREE CHOICE. The rim was built at 35.552 -- the pitch line
    differential deducted twice -- and the first attempt at teeth cut from the rim as drawn, on the
    grounds that 0.69 mm is 1.8% of torque. That was wrong, for reasons outside the part: BOM S2b's
    idler is a BOUGHT 29T pulley measuring 72.48 over the tips, and BOM K1's belt is a BOUGHT 742 mm
    loop, which is 2*pi*36.923 + 2*255 to 0.03 mm. A belt cann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
    [A7_DriveBracket_Idler.stl, KneeExo_v6.FCStd, KneeExo_v6_R.FCStd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]
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2026-10-03 Turn the motor over, and the 124 g of screw that bought
    The motor hung off the bracket's far face with the ball screw running the
    whole way past it, so 82 mm of SFU1620 existed only to reach a nut that
    never travelled there: screw 257 -> 175 mm, about 124 g of steel off the
    thigh. Flipping it also puts the motor's free end -- the shaft stub, the
    magnet, the rear bolt circle -- where the link belt used to be, which is
    the only space in the pack big enough for the controller.
    433 moves the motor Y 217..291 -> 228..302, the link belt 302..314 ->
    208..220, rebuilds the screw with its 8 mm journals, and reworks the
    bracket around it (139.7 -> 136.3 cm3). Four separate attempts split the
    bracke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
    [433_drive_flip.py, 434_odrive_mount.py]
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2026-10-03 The board was 6.6 mm inside the patient's leg, and nothing could see it
    The 107-pose sweep came back with five pairs that were not there before,
    three of them mine, and one of them was not a modelling slip.
    THE LIMB IS NOT WHERE THE MODEL SAYS IT STOPS. REF_Thigh is truncated at
    Y 300. The controller sits at Y 311. So every interference check in this
    repository -- the full sweep included -- reported the board, the mount and
    the new nose clear of the leg, because the leg simply stops being
    modelled there. The real thigh does not stop 30 cm above the knee; it
    gets thicker toward the hip.
    Measured against 399_drivecap.py's own cylinder instead, extended over
    the whole drive:
    pod tube, as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
    [433_drive_flip.py, 434_odrive_mount.py]
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2026-10-03 The cover was 2.9 mm inside the patient's sleeve, and a cylinder hid it
    Asked at the bench whether P25_MotorNacelle could swing out and lock
    further from the leg for a fatter leg. The nacelle IS the closest part to
    the limb, so the instinct was right, and answering it found something the
    whole repository was blind to.
    EVERY LIMB CUT HERE IS A CYLINDER AND THE LEG IS A TAPER. 399_drivecap.py
    carves the cladding with cylinders of r 87.9 and r 85.0 about the limb
    axis -- correct at the top of REF_Thigh and 20 mm too generous at the
    knee. A cylinder cannot express "3 mm clear of the leg" on a conical leg,
    so nothing had ever asked whether the 3 mm neoprene sleeve of BOM S5 fits
    under the drive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
    [A7_DriveBracket_Idler.stl, P22_DriveCap.stl, P25_MotorNacelle.stl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]
2026-10-03 A trim in a later script is a trim an earlier one can undo
    The left leg came back 0.41 cm3 inside the patient's sleeve while the
    right -- its own mirror -- came back clean, which should be impossible.
    The cause is worth more than the fix: 439_limb_trim.py cut the cover back
    from the leg AFTER 434_odrive_mount.py drew it, and 434's bell spans
    Y 289..334 and is re-fused on every run. Re-running 434 for any reason
    put the cover straight back inside the sleeve, removed nothing, raised
    nothing, and left the two legs disagreeing. I did exactly that, to print
    one diagnostic line.
    So the envelope moves to tools/limbcone.py -- one authority, the same
    reason tools/markframe.py exists after four copie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
    [P25_MotorNacelle.stl]
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2026-10-04 Two IMUs get a frame, and the list of what moves gets one authority
    The IMU work from 441 built: a platform and pocket on each cuff
    (442_imu_mounts.py), a lid over each, and the documentation that makes
    them mean something.
    THE POCKET IS THE MEASUREMENT, NOT THE RETENTION. Every number 441
    computes -- sitting against lying with the knees up at 45 degrees,
    standing against inverted at 180 -- is an angle in the SENSOR's frame.
    A module taped on at whatever angle the tape allowed makes all of them a
    guess. The pocket's long axis runs along the limb, so the module's X is
    the segment's own axis. ADDITIVE, not subtractive: these are the two
    parts that bear on the patient and 409_cuffs.py sized th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
    [P25_MotorNacelle.stl, P27_ControllerMount.stl, P28a_IMUCover.stl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]
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2026-10-05 457: sweeps pass on both legs, STLs re-exported
    107-pose interference sweep via tools/sweep.py (sharded -- running
    601_verify_fast.py bare is the 12x-slower path, which is why my first attempt
    looked hung):
    left 107 poses, 10 shards, 9.3 min
    right 107 poses, 10 shards, 16.1 min
    Both return exactly the six intended pairs and identical volumes to three
    decimals: three reference limb segments overlapping each other, and the three
    fairing mounts inside the shell they carry. Nothing from the knee rebuild
    appears at any angle from -2 to +104, which is the test that matters for a joint
    whose bearings just moved.
    902_doc_audit: volume claims off by more than 5% now 0 -- README's "P2a 148 cm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
    [P1_KneeYoke.stl, P2a_KneeHub_Pulley29T.stl]
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2026-10-05 459: the pod relief cut the nose off the nacelle -- guarded and reverted
    Caught because the bench looked at v8 and said nothing had changed. The one
    thing that WAS visibly different was wrong: P25_MotorNacelle tapers to a dome
    centred ON the motor axis, so over Y 194..202 its entire cross-section lies
    inside the r 32.67 relief bore. The cut did not shave a wall, it amputated the
    end of the part, and everything below fell off as a fragment I then discarded as
    "0.058 cm3 of loose fragment" without asking what it was. The BOM describes P25
    as "prints nose-down on its domed end". There was no dome left.
    The relief now runs a WHOLE-SECTION check before cutting anything: for each 4 mm
    slab in ran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
    [KneeExo_v8.FCStd]
2026-10-05 459: the 38T drive does not fit the pod, by 7.5 cm3
    My clearance check named its suspects -- the screw, the foot, the two pulleys --
    and left out A7b_LinkBelt. So it reported 0.271 cm3 of pulley fouling the
    nacelle and missed 6.917 cm3 of BELT doing the same thing. The 107-pose sweep
    found it. A check you write by naming the suspects only finds the suspects, so
    it now tests every part this script touches against everything in the document.
    The real number: the belt's back sits at r 33.47 from the motor axis (tip 29.67
    plus 3.8 of belt) and P25's bore there is r 29.7 -- 3.8 mm of interference the
    whole way round. 446_sfu1605_set.py predicted 0.2 mm from the pulley's pitch
    radius alone and wa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
    [KneeExo_v8.FCStd]
2026-10-05 459: the pod now clears the 38T drive -- 0 unresolved
    Three corrections on top of each other, each found by the next check.
    GUARD_R was still 446's wrong number. It used the pulley's PITCH radius plus 2
    where the belt's back is tip + the belt's own 3.8 mm thickness: r 34.47, not
    32.67. 446 predicted 0.2 mm of pod interference and the truth was 3.8 mm.
    The bay has to be GROWN before it is cut. P25's dome sits on the motor axis, so
    a relief bore amputates the end of the part -- the previous commit's guard
    caught that and refused; this fuses a bay wall first, so the dome stays attached
    through it, which is the same move 457 needed for the knee capstan.
    And the relief is the belt's own STADIU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
    [A7_DriveBracket_Idler.stl, KneeExo_v8.FCStd, P1_KneeYoke.stl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]
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2026-10-05 464: the motor pod is not a bulge, it is a cliff -- blended
    The complaint was the motor box hanging off separately. Three measurements said
    there was nothing to fix, and all three were looking in the wrong place:
    * it does not stick out. Everything above the knee lies between r 145 and
    r 161, and the cladding is only 3-7 mm proud of its contents (463).
    * merging the cladding saves nothing. P21, P22 and P25 have ZERO mutual
    overlap -- fusing them recovers 0.00 cm3. There are no doubled walls.
    * and it is 230 g, not the 531 I quoted, because the solid volume is 418 cm3
    but it prints at two walls and low infill. I applied solid PETG density to a
    part that is mostly air.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
    [KneeExo_v8.FCStd, P21_FairingThigh.stl, P25_MotorNacelle.stl]
2026-10-05 464/460: the ramp is 31 degrees, and I had quoted 28
    460 caught it within a minute of being extended to cover the blend. My own
    script printed "steepest face now 33 degrees" and I reported 28.4 -- I had taken
    the 2.7 mm per 5 mm from the BODY of the ramp and quoted it as the whole,
    ignoring the 3.3 mm step at the top that the same line of output named. That is
    the third time today a number has drifted between the model and the prose, and
    the first time a standing check caught it instead of the user.
    The step was real, not just mis-stated: the blend arrived at r 156.6 where the
    pod is already 158, so the pod's own leading face poked 1.4 mm through whatever
    the blend was doing. Landing the la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
    [KneeExo_v8.FCStd, P21_FairingThigh.stl, P25_MotorNacelle.stl]
2026-10-06 Revert the thigh blend, and retract 462's screw recommendation as wrong
    The bench looked at v8 and said two things: it looks bad, and the screw never
    moved. Both were right.
    THE SCREW NEVER MOVED. 462 recommended centring it on the rail and called it
    "the real win"; 463 then ASSUMED it was centred while searching for the motor's
    position; 459 and 464 never did it. Worse, checking why exposed that the
    recommendation was wrong: the carriage does not reach from the nut to the RAIL,
    it reaches from the nut to the one belt strand it clamps, at X -37.3. From the
    screw's X -62 that is 24.7 mm. From X 0 it would be 37.3 -- half as much again.
    Centring the screw makes the carriage worse. Retracted i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
    [KneeExo_v8.FCStd, P21_FairingThigh.stl, P25_MotorNacelle.stl]
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
